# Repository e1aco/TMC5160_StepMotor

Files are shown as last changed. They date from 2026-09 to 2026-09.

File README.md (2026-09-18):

# TMC5160 步进电机驱动器

基于 STM32H750 + TMC5160 的高性能闭环步进电机驱动器，支持双电机独立控制，通过 CAN 总线通信。

## 项目状态

- ✅ 硬件验证完成（SPI 模式）
- ✅ CAN 通信协议实现
- ✅ 闭环控制（编码器反馈 + 补步）
- ✅ 散热优化：3A 持续运行温度 ≤ 70℃

## 硬件规格

| 参数 | 规格 |
|:-----|:-----|
| 主控芯片 | STM32H750VBT6（注：建议改用 STM32F103 系列） |
| 驱动芯片 | TMC5160 |
| 电机型号 | 57CME13 闭环步进电机 |
| 驱动模式 | SPI 模式（SD_MODE=0, SPI_MODE=1） |
| 采样电阻 | 0.05Ω / 1W |
| MOS 管 | AOD4126 |
| 时钟频率 | 14MHz（TMC_CLK） |
| SPI 频率 | ≤8MHz（TMC5160 最高 16/2=8MHz） |
| 通信接口 | CAN FD |
| 驱动电流 | 最大 3A（持续运行温度 ≤ 70℃） |

> **主控选型建议**：TMC5160 驱动芯片最高时钟 16MHz，SPI 最高 8MHz，无需使用 STM32H750 这类高性能芯片。建议改用 **STM32F103** 系列（如 STM32F103C8T6），成本更低且完全满足需求。当前使用 H750 属历史遗留原因。

## 软件特性

- **SPI 完全控制**：通过 SPI 接口配置 TMC5160 所有参数
- **双电机支持**：可独立控制两个电机（U1/U2）
- **多种运动模式**：
  - 绝对位置定位
  - 相对位置移动（正转/反转）
  - 速度模式持续旋转
  - 停止/刹车
- **闭环控制**：编码器反馈 + PID 补步（预留）
- **运动参数组**：预定义 4 组运动参数（低速精准/中速普通/快速/高速）
- **PID 在线调参**：支持通过 CAN 实时调整 PID 参数
- **状态反馈**：实时上报位置、状态标志、运动阶段

## CAN 通信协议

### 1. 接收命令协议 (CAN ID: `0x1AA55F42`)

| 字节索引 | 含义 | 说明 |
|:---|:-----|:-----|
| [0-3] | 值 (int32) | 4字节小端（低字节在前），含义由命令码决定 |
| [4] | 命令码 | 见下方命令码表 |
| [5] | 电机选择 | 0x01=U1, 0x02=U2, 0x06=所有电机 |
| [6] | 参数/分组 | 0x01~0x04=运动参数组（命令0x01~0x05），0x01~0x06=PID参数类型（命令0x06） |
| [7] | 校验和 | 前7字节累加取低8位 |

#### 命令码定义

| 命令码 | 名称 | [0-3] 含义 | [6] 含义 |
|:---:|:-----|:---|:---|
| 0x01 | 绝对位置移动 | 目标位置（微步） | 运动参数组 (0x01~0x04) |
| 0x02 | 相对位置正转 | 移动步数 | 运动参数组 (0x01~0x04) |
| 0x03 | 相对位置反转 | 移动步数 | 运动参数组 (0x01~0x04) |
| 0x04 | 速度模式 | 目标速度（微步/秒） | 运动参数组 (0x01~0x04) |
| 0x05 | 停止/刹车 | 0（忽略） | 运动参数组 (0x01~0x04) |
| 0x06 | PID调参 | 参数值（Q16或整数） | PID参数类型 (0x01~0x06) |

#### 运动参数组定义 (命令 0x01~0x05 使用)

| 参数组 | 说明 | VMAX | AMAX | 典型场景 |
|:---:|:-----|-----:|-----:|:---|
| 0x01 | 低速精准 | 5,000 | 1,000 | 精准定位 |
| 0x02 | 中速普通 | 20,000 | 5,000 | 日常运动 |
| 0x03 | 快速 | 50,000 | 10,000 | 快速移动 |
| 0x04 | 高速 | 100,000 | 20,000 | 长距离搬运 |

#### PID参数类型定义 (命令 0x06 使用)

| 参数类型 | 含义 | 值格式 | 默认值 |
|:---:|:-----|:---|---:|
| 0x01 | Kp（比例系数） | Q16定点数 | 8192 (0.5) |
| 0x02 | Ki（积分系数） | Q16定点数 | 2048 (0.125) |
| 0x03 | Kd（微分系数） | Q16定点数 | 4096 (0.25) |
| 0x04 | out_max（最大输出速度） | 直接整数 | 50000 |
| 0x05 | out_min（最小输出速度） | 直接整数 | -50000 |
| 0x06 | integral_max（积分限幅） | 直接整数 | 32768 |

> **Q16定点数**：实际值 = Q16值 / 65536。例如 Kp=0.5 → Q16值 = 0.5 × 65536 = 8192。

### 2. 反馈响应协议 (CAN ID: `0x1AA55F43`)

| 字节索引 | 含义 | 说明 |
|:---|:-----|:-----|
| [0-3] | 值 (int32) | 4字节小端，含义由 byte[6] 决定 |
| [4] | 标志/参数类型 | 运动反馈=状态标志位，调参反馈=参数类型 |
| [5] | 电机选择 | 0x01=U1, 0x02=U2 |
| [6] | 反馈类型 | 0x01~0x05=运动反馈，0x06=调参反馈 |
| [7] | 校验和 | 前7字节累加取低8位 |

#### 运动反馈 (byte[6] = 0x01~0x05)

| 字节索引 | 含义 | 说明 |
|:---|:-----|:-----|
| [0-3] | 位置值 (int32) | 当前电机 XACTUAL 绝对位置 |
| [4] | 状态标志位 | bit0=到位, bit1=堵转, bit2=过温, bit3=驱动错误, bit4=SPI异常 |
| [5] | 电机选择 | |
| [6] | 运动阶段 | bit0=加速, bit1=匀速, bit2=减速, bit3=归零等待, bit4=静止锁轴 |
| [7] | 校验和 | |

**状态标志位 (byte[4]) 详解：**
```
bit0 → 0=运动中，1=已到位
bit1 → 0=正常，1=堵转/失步
bit2 → 0=正常，1=过温告警
bit3 → 0=正常，1=驱动错误
bit4 → 0=SPI正常，1=SPI通讯异常
bit5-7 → 保留
```

#### 调参反馈 (byte[6] = 0x06)

| 字节索引 | 含义 | 说明 |
|:---|:-----|:-----|
| [0-3] | 参数值 (int32) | 刚设置的参数值 |
| [4] | 参数类型 | 0x01=Kp, 0x02=Ki, 0x03=Kd, 0x04=out_max, 0x05=out_min, 0x06=integral_max |
| [5] | 电机选择 | |
| [6] | 固定 0x06 | 标识为调参反馈 |
| [7] | 校验和 | |

#### 反馈发送规则

| 命令码 | 发送时机 |
|:---:|:---|
| 0x01/0x02/0x03 | 立即发送启动反馈 + 到位后发送到位反馈 |
| 0x04/0x05 | 仅立即发送一次 |
| 0x06 | 立即发送调参确认反馈 |
| 异常 | 堵转/过温/驱动错误/SPI异常状态变化时，5ms定时器触发发送 |

## 构建说明

### 环境要求

- CMake 3.20+
- ARM GCC 工具链 (`arm-none-eabi-gcc`)
- STM32CubeMX（可选，用于重新生成初始化代码）

### 编译步骤

```bash
cd Firmware/TMC5160H7Cmake_StepMotor

# 使用 CMake Presets 配置（推荐）
cmake --preset gcc-arm-none-eabi
cmake --build build

# 或手动配置
mkdir build && cd build
cmake -DCMAKE_TOOLCHAIN_FILE=../cmake/gcc-arm-none-eabi.cmake ..
make -j4
```

### 烧录

- 使用 STM32CubeProgrammer 通过 SWD 烧录
- 或使用 J-Link：`JLinkExe -device STM32H750VBTx -if SWD -speed 4000`

## 目录结构

```
ELACO_StepMotorTMC5160/
├── Firmware/
│   └── TMC5160H7Cmake_StepMotor/
│       ├── CMakeLists.txt          # 主 CMake 配置
│       ├── CMakePresets.json        # CMake 预设
│       ├── Core/                    # STM32 HAL 核心代码
│       │   ├── Inc/                 # 头文件
│       │   └── Src/                 # 源文件
│       ├── Drivers/                 # STM32 HAL 驱动库
│       ├── module/
│       │   ├── app/                 # 应用层
│       │   │   ├── motor_ctrl.c     # 电机控制接口
│       │   │   └── closed_loop.c    # 闭环控制模块
│       │   ├── algo/                # 算法层
│       │   │   └── pid.c            # PID 算法
│       │   └── drv/                 # 驱动层
│       │       ├── tmc5160.c        # TMC5160 驱动
│       │       └── can.c            # CAN 驱动
│       ├── SEGGER_RTT/              # 调试输出
│       ├── cmake/                   # CMake 工具链
│       └── test/                    # 测试代码
├── Hardware/
│   └── StepMotor_2Routes_TMC5160/   # Altium Designer 硬件设计
├── Reference/                       # 参考资料
└── README.md
```

## 理论参考

### 1. 原理图设计要点

1. **电源设计**：VSA 与 VS 由一路供电时最安全；若 VS 超过 24V，VSA 应使用单独的开关电源
2. **MOS 管选型**：
   - 选择适合电机电压（峰值+5~10V余量）和最大电流的 MOSFET
   - Vth 选择 10V 以内（TMC5160 驱动电压约 10V）
   - 根据米勒电荷选择栅极电阻（AOD4126: 10nC → 10Ω 栅极电阻）
3. **保护电路**：BM 引脚到地建议添加 TVS 二极管，避免低于 -5V 的峰值

### 2. PCB 布线要点

1. 采样电阻和滤波电容尽可能靠近功率 MOSFET
2. TMC5160 靠近 MOSFET 放置，短线互连
3. 所有 GND、GNDA、GNDD 连成公共地
4. 做好芯片散热（内部 LDO 功耗较大）
5. MOSFET 栅极走线短而直、较宽

### 3. TMC5160 配置

- **SPI 模式**：CPOL=1, CPHA=1（模式 3）
- **数据帧**：40 位（5 字节），CS 片选定界
- **时钟配置**：14MHz 方波（84MHz / 6 = 14MHz）

## 已解决问题

- ✅ 采样电阻修改为 0.05Ω / 1W
- ✅ CE3 电容 PCB 封装修正
- ✅ 栅极电阻焊接（防止 MOS 管栅极悬空导通）
- ✅ SPI 通信实现
- ✅ CAN 通信协议实现
- ✅ 闭环控制移植
- ✅ 散热优化（3A 持续运行 ≤ 70℃）

## License

MIT

---

欢迎讨论学习，如有问题请提 Issue。

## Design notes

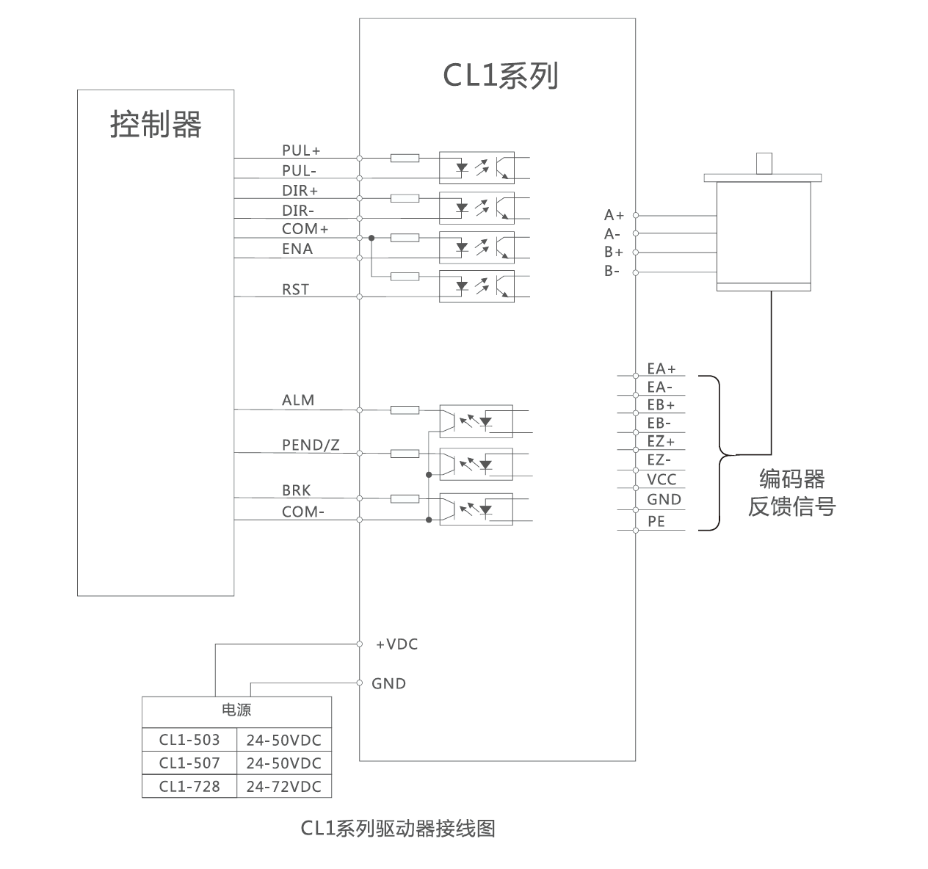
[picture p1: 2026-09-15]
Reference/接线.png

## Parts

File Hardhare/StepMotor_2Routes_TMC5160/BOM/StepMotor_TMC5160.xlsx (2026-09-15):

Comment | Description | Designator | Footprint | LibRef | Quantity | 物料代码 | 链接
2.2uF/16V | 贴片电容 | C1, C8, C17, C18, C46, C53 | C 0603_L | C | 6 | A00600123 | A03400001
104/50V | 贴片电容 | C2, C3, C4, C15, C37, C47, C48, C49, C56, C59, C10, C12, C39, C40, C42, C44C10, C12, C39, C40, C42, C44,C19, C20, C21, C22, C23, C24, C25, C26, C27, C29, C30, C31, C32, C33,C58 | C 0805_L | C | 31 | A03400669
470nF/50V | 贴片电容 | C5, C6, C7, C13, C14, C50, C51, C52, C54, C55 | C 0603_L | C | 10 | A00600157 | https://item.szlcsc.com/87156.html?c=SO&qhclickid=5d7fd4ccac5a9837&alichlgref=https%3A%2F%2Fso.szlcsc.com%2F
106/50V | 贴片电容 | C9, C11, C38, C41, C43, C45 | C 0805_M | C | 6 | A03400304
22nF/50V | 贴片电容 | C16, C57 | C 0603_L | C | 2 | A00600158 | https://item.szlcsc.com/21834.html?fromZone=s_s__%252222nf%2522&c=SO&qhclickid=5d7fd4ccac5a9837
22P/16V | 贴片电容 | C34, C35 | C 0603_M | C | 2 | A00600114
220uF/50V | 直插电解电容 | CE1, CE2, CE4, CE5 | CAP 5.0*10*12.5 - BK | CE | 4 | A00600159 | https://item.szlcsc.com/356226.html?c=SO&qhclickid=5d7fd4ccac5a9837
470uF/50V | 直插电解电容 | CE3 | CAP 5.0*10*20 | CE | 1 | A01400137 | 无库存 | https://item.szlcsc.com/54596843.html?fromZone=s_s__%2522470uF%252F50V%2522
1N4148W |  | D1, D2, D4, D5, D6, D7, D8, D9, D12, D13, D15, D16, D17, D18, D19, D20 | SOD-123 | 1N4148W_C7420318 | 16 | A01000027 | https://item.szlcsc.com/8397140.html?fromZone=s_s__%25221n4148%2522&c=SO&qhclickid=5d7fd4ccac5a9837
SMAJ28CA | TVS保护 | D3, D14 | DIODE-SMB | TVS | 2 | A01000028 | https://item.szlcsc.com/159561.html?fromZone=s_s__%2522smaj28ca%2522&c=SO&qhclickid=5d7fd4ccac5a9837
SS310 | 肖特基二极管 | D11 | SMA | SS34 | 1 | A01000029 | https://item.szlcsc.com/8397186.html?fromZone=s_s__%2522ss310%2522&c=SO&qhclickid=5d7fd4ccac5a9837
180uF/50V | 贴片电解电容 | E1 | CM E(8*10.2) | CE_SMD | 1 | A00600160 | https://item.szlcsc.com/505695.html?fromZone=s_s__%2522180uf%252050v%2522&c=SO&qhclickid=5d7fd4ccac5a9837
HDR-1X2 | 2P接插件 | JP1, JP4 | VH3.96-LI-2P | Header 2 | 2 | A01300061
HDR-1X4 | 4P接插件 | JP2, JP5 | KF350-4P | Header 4 | 2 | A00700015 | https://item.szlcsc.com/376627.html?c=SO&qhclickid=5d7fd4ccac5a9837
HDR-1X4 | 4P接插件 | JP3 | HDR2.54-LI-4P | Header 4 | 1 | A03400323
HDR-1X6 | 6P接插件 | JP6-7 | XH2.54-LI-6P | Header 6 | 1 | A03400322
68uH | 功率屏蔽电感 | L1 | IND-SMD_L5.7-W5.2_GSM0530 | L-CDRH | 1 | A01300125 | https://item.szlcsc.com/56628172.html?fromZone=s_s__%25226.8uh%2522&c=SO&qhclickid=5d7fd4ccac5a9837
红色 | 贴片LED | LED1 | LED 0805G | LED-SMD | 1 | A03400295
AOD4126 | N沟场效应管 | Q1, Q2, Q3, Q4, Q5, Q6, Q7, Q8, Q9, Q10, Q11, Q12, Q13, Q14, Q15, Q16 | TO252 | 2SK3615 | 16 | A01400174 | https://item.szlcsc.com/461587.html?fromZone=s_s__%2522aod4126%2522&c=SO&qhclickid=5d7fd4ccac5a9837
10R 1% | 贴片电阻 | R1, R2, R4, R5, R12, R13, R15, R16, R42, R43, R45, R46, R53, R54, R56, R57 | R 0603_L | R | 16 | A03400177
2R2 1% | 贴片电阻 | R3, R6, R44, R47 | R 0603_L | R | 4 | A00500176 | https://item.szlcsc.com/2177928.html?fromZone=s_s__%25222.2r%25200603%2522&c=SO&qhclickid=5d7fd4ccac5a9837
47R 1% | 贴片电阻 | R7, R11, R18, R25, R48, R52, R59, R67 | R 0603_L | R | 8 | A00500177 | https://item.szlcsc.com/3180687.html?fromZone=s_s__%252247r%2522&c=SO&qhclickid=5d7fd4ccac5a9837
0R | 贴片电阻 | R8, R9 | R 2512_L | R | 2
50mR/3W | 贴片电阻 | R10, R22, R51, R64 | R 2512_L | R | 4 | A00500178 | https://item.szlcsc.com/3159229.html?fromZone=s_s__%252250mr%25203w%2522&c=SO&qhclickid=5d7fd4ccac5a9837
0R/NC | 贴片电阻 | R14, R55 | R 0603_L | R | 2
100R | 贴片电阻 | R17, R58 | R 0603_L | R | 2 | A03400179
4.7K | 贴片电阻 | R19, R23, R24, R26, R28, R32, R33, R60, R61, R65, R66 | R 0603_L | R | 11 | A00500056
3K | 贴片电阻 | R27 | R 0603_L | R | 1 | A03400147
1K | 贴片电阻 | R34, R36, R37, R39, R68, R69, R72, R73 | R 0603_L | R | 8 | A03400181
120R | 贴片电阻 | R35, R38, R70, R71, R75, R76 | R 0603_L | R | 6 | A03400167 | 无库存 | https://item.szlcsc.com/3180501.html?fromZone=s_s__%2522120r%25200603%2522&c=SO&qhclickid=5d7fd4ccac5a9837
0R/NC | 贴片电阻 | R40, R41 | R 0805_L | R | 2
10K | 贴片电阻 | R74 | R 0603_L | R | 1 | A03400318
SW-PB | 微动开关 | S1 | SW_PB2_A1 | SW-PB | 1
TMC5160A-TA-T |  | U1, U2 | TQFP-48_L7.0-W7.0-P0.50-LS9.0-BL-EP | TMC5160A-TA-T | 2 | A01800052 | https://item.szlcsc.com/532372.html?fromZone=s_s__%2522TMC5160%2522&c=SO&qhclickid=5d7fd4ccac5a9837
STM32F407ZET6 | STM32F407ZET6 | U3 | LQFP-144_20x20x05P | STM32F407ZET6 | 1 | A03400014
XDDB-1518-0932 |  | U4, U8 | DDSUB-TH_HYC06-HDR15B-060 | XDDB-1518-0932 | 2 | A01300126 | https://item.szlcsc.com/8568600.html?fromZone=s_s__%2522XDDB-1518%2522&c=SO&qhclickid=5d7fd4ccac5a9837
XL1509-5.0E1 | 功能类型:降压型;工作电压:4.5V~40V;输出电压:5V;输出电流:2A;输出类型:固定; | U5 | SOIC-8_L5.0-W4.0-P1.27-LS6.0-BL | XL1509-5.0E1 | 1 | A01800053 | https://item.szlcsc.com/44273613.html?fromZone=s_s__%2522XL1509%2522&c=SO&qhclickid=5d7fd4ccac5a9837
AM26LV32EIDR |  | U6 | SOIC-16_L9.9-W3.9-P1.27-LS6.0-BL | AM26LV32EIDR | 1 | A03400796 | https://item.szlcsc.com/545744.html?fromZone=s_s__%2522AM26LV32%2522&c=SO&qhclickid=5d7fd4ccac5a9837
SN65HVD230QDR | 类型:CAN收发器;数据速率:1Mbps; | U7 | SOIC-8_L5.0-W4.0-P1.27-LS6.0-BL | SN65HVD230QDR | 1 | A03400034
ISL8490IBZ-T |  | U9 | SOIC-8_L4.9-W3.9-P1.27-LS6.0-TL | ISL8490IBZ-T | 1 | A03400737
AMS1117-3V3 | 三端稳压芯片 | V1, V2 | SOT223_L | AMS1117 | 2 | A03400043
8MHz | 2脚无源脚晶振 | X1 | OSC 6035-2P | XTAL-2P | 1 | A01200078 | 无库存
AMS1085CM-3.3 |  |  |  |  |  |  | https://item.szlcsc.com/46911.html?fromZone=s_s__%2522AMS1085cm%2522&c=SO&qhclickid=5d7fd4ccac5a9837
AOT470 |  |  |  |  |  |  | https://item.szlcsc.com/43270.html?fromZone=s_s__%2522aot470%2522&c=SO&qhclickid=5d7fd4ccac5a9837

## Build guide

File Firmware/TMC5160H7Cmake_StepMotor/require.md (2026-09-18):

<!-- 维护模式：本文件由 AI 维护，用户不再手动编辑。require 内容（芯片/引脚/工具链/全局目标）由访谈获取；风险确认与时序实测数据由用户直接发给 AI 登记（见 details/init.md、details/risk.md、details/tim.md）。用户口头声明变更（如"改引脚""目标变了"）→ AI 按「硬重读门」重读。-->
# 硬件资源池 (Hardware Pool)
芯片: STM32H750VBT6 (LQFP100, Cortex-M7)
晶振频率: 8 MHz (HSE, PH0/PH1)
芯片 RAM: DTCMRAM 128 KB (0x2000_0000, .data/.bss/stack)；另有 AXI 512K / RAM_D2 288K / RAM_D3 64K / ITCM 64K 未用
芯片 Flash: 128 KB (0x0800_0000)
栈大小 (Stack_Size): 1024 B (_Min_Stack_Size=0x400, 链接脚本)
关键器件:
  - 驱动芯片: TMC5160 ×2 (U1/U2, SPI 模式)
  - 外部 MOS: AOD4126
  - 采样电阻 RS: 0.05 Ω
  - 步进电机: 57CME13 (2 相, 1.8°, 4A, 1.3N·m；详细参数见 .cl/memory/config.md)
  - 编码器: 光编 1000 PPR (×4=4000cpr, 用于闭环反馈)

# 引脚固定映射表 (Pin Mapping)
> 必须为 Markdown 表格（首行表头 + `|---|` 分隔行），禁止裸文本行。

| 功能网标 | 引脚号 | 外设功能 | 说明 |
| :--- | :----- | :--- | :--- |
| HSE_IN | PH0 | RCC_OSC_IN | 8MHz 晶振输入 |
| HSE_OUT | PH1 | RCC_OSC_OUT | 8MHz 晶振输出 |
| LED_MCU | PA4 | GPIO_Output | 用户指示灯, 默认高 |
| U1_DRV_ENN | PA10 | GPIO_Output | TMC5160 #1 驱动使能(低有效), 默认高 |
| U1_SPI_SCN | PA11 | GPIO_Output | TMC5160 #1 SPI 片选(低有效), 默认高 |
| SWDIO | PA13 | DEBUG_JTMS | SWD 调试 |
| SWCLK | PA14 | DEBUG_JTCK | SWD 调试 |
| U2_DRV_ENN | PA15 | GPIO_Output | TMC5160 #2 驱动使能(低有效), 默认高 |
| FDCAN2_RX | PB12 | FDCAN2_RX | CAN 总线接收 |
| FDCAN2_TX | PB13 | FDCAN2_TX | CAN 总线发送 |
| USART1_TX | PB14 | USART1_TX | 调试串口发送 |
| USART1_RX | PB15 | USART1_RX | 调试串口接收 |
| SPI3_SCK | PC10 | SPI3_SCK | TMC5160 SPI 时钟 |
| SPI3_MISO | PC11 | SPI3_MISO | TMC5160 SPI 数据输入 |
| SPI3_MOSI | PC12 | SPI3_MOSI | TMC5160 SPI 数据输出 |
| U2_SPI_SCN | PD3 | GPIO_Output | TMC5160 #2 SPI 片选(低有效), 默认高 |
| TMC_CLK | PD14 | TIM4_CH3 | TMC5160 外部时钟(PWM 输出 15MHz) |

# 工具链池 (Toolchain Pool)
构建体系: cmake
CMake 工程: 工程根=本目录; target=TMC5160H7_StepMotor; 工具链文件=cmake/gcc-arm-none-eabi.cmake（cmake_build.py 自动探测）; 构建目录=build_cl（与 CLion 的 build/ 隔离）
编译指令: python tools/cmake_build.py <工程根> [--define 宏]   # RESULT 行=真相判据，产物 hex/elf 落 build_cl/（唯一权威 details/build.md）
IDE/编译器: CMake + GCC (arm-none-eabi-gcc) + Ninja（STM32CubeCLT）；CLion 打开同一工程用其自有 Profile
芯片型号: STM32H750VBT6
优化等级: -O0 -g3（cmake_build.py 默认 Debug 构建；Release=-Os -g0 未启用）
FPU: 单精度 + 双精度 (Cortex-M7 DP-FPU)
CubeMX 版本: 6.17.0, FW_H7 V1.13.0

# 调试与烧录 (Debug/Flash)
调试器: ST-Link (SWD, PA13/PA14)
调试回传接口: USART1 (PB14/PB15, 115200, 独立 CH340 → PC 枚举为 COMx，监听用 .cl/capture/start_mon.ps1)
启动横幅: [BOOT] TMC5160H7 StepMotor
烧录工具: ST-Link + OpenOCD (首选) / J-Link (备选)
烧录指令: python tools/openocd_flash.py --flash <工程根>\build_cl\TMC5160H7_StepMotor.hex --target stm32h7x
J-Link 烧录: python tools/jlink_flash.py --flash <工程根>\build_cl\TMC5160H7_StepMotor.hex --target stm32h750vb
复位/运行: python tools/openocd_flash.py --reset --target stm32h7x
> 残留进程兜底: python tools/openocd_flash.py --kill
> 调试通道: 主=USART1 115200；J-Link RTT 已实现但默认关（cl_config RTT_DBG=0，遥测不占 CAN 总线）；FDCAN2(500kbps) 用于命令/反馈协议

# 项目全局目标 (Global Goal) — 需求锁锚点，禁静默降级
> 每行 = 量化目标（值+单位）+ 验收判据 + 来源。AI 生成/调参/验收一律对照本节；认为不可达时禁止自行降级，须带证据请你决定（SKILL.md 约束 11）。

- 一句话定位: 双 TMC5160 独立电机控制，CAN 指令驱动，支持绝对位置/相对位置/速度三种运动模式
- 精度: 0.09°/count（光编 1000PPR ×4=4000cpr；闭环定位精度由编码器+控制算法决定，待调定后实测）
- 速度: 最高 600rpm, 加减速由 TMC5160 内部速度规划（VDCOL/TCOOLTHRS 等），暂不外部干预 | 来源: 你
- 控制周期: 待定（CAN 协议后续定义，位置环周期由 TMC5160 内部扫描）| 来源: 待定
- 负载: 待实测确定（电机 57CME13, 保持力矩 1.3N·m, 转子惯量 0.3kg·cm²）| 来源: 待实测确定
- 接口/通信: CAN 500kbps, 协议后续定义 | 来源: 待定
- 电源: 24VDC（电机建议 36V, 降额使用）| 来源: 你
- 编码器: 光编 1000PPR, ×4正交解码=4000cpr (ENC_CONST=12.8 对齐 51200微步/圈), 用于闭环反馈 | 来源: 你, 实测验证
- 验收判据: 待定（由你确定）| 来源: 你
- 优先级: 待定（由你确定）| 来源: 待定
- 首版范围 (MVP): 待定 | 来源: 待定
- 待实测确定项: 精度指标、负载工况、控制周期、验收判据、优先级、MVP 范围

# 风险与假设日志 (Risk & Assumption Log) — AI 维护，人工审核重点
> 每个 /cl run|code 收尾标 [x]/[c]/[!] 前 AI 自查 9 类高风险区并登记（规则/词表唯一权威 = details/risk.md）。无风险的任务条目末尾标 `风险:无`。

| 日期 | 任务 | 类别 | 位置 | 假设/风险点 | 可追溯到? | 状态 |
| :--- | :--- | :--- | :--- | :--- | :--- | :--- |
| 2026-09-17 | 全工程 | 安全/看门狗 | 全工程 | 无 IWDG；主循环/外设挂死或堵转时电机持续通电（已确认工程无 IWDG/WWDG） | 缺口 | [!] 待实测 |
| 2026-09-18 | 组5超高速 | 硬件时序/电气 | module/drv/tmc5160.c:94 | 组5 VMAX=2863311(50rps)在24V+传送带下必失速丢步（实测边界1200<stall≤1500rpm，U2先丢），丢步后开环位置丢失、无限位则无法0x09恢复，只能断电重建零点 | 实测 | [x] 已解决（组5已降600rpm生产档并验证PASS） |
| 2026-09-18 | 组6极限运行 | 失败路径/恢复 | module/drv/tmc5160.c:95 | 组6=1442rpm逼近U2失速边界(1471,1481]，属故意高风险运行：失速→位置丢失→断电重建；仅有人值守测试，生产帧禁用param=6，每次用后查失步位 | 推演链 | [✓] 人工确认（用户10+次复测干净，生产禁用+值守+用后查失步位三条防线已固化） |

> 类别词表(9类): 硬件时序/电气 | 实时性/竞态 | 数值溢出/定点 | 寄存器/手册 | 失败路径/恢复 | 内存/栈 | 安全/掉电 | 时序参数/经验值 | UB/可移植
> 可追溯到?: 手册 / 实测 / 推演链 / 缺口
> 状态: [ ] 待人工确认 / [✓] 人工确认 / [!] 待实测 / [x] 已解决（可归档删除）

# 时序测量表 (Timing Budget) — AI 维护，外部实测需人工回填

## 前置配置区
> 默认指标（预算比例/总利用率上限/绝对裕量/测试周期/词表）为 skill 级默认，唯一权威见 `details/tim.md`「默认指标」；项目覆盖在此改。
- 时序测试点 IO: PD14 (TMC_CLK, TIM4_CH3) — 可翻转供 Saleae/示波器捕获
- 探针默认位置: 函数级（ISR 入口/出口），语句级由条目位置列自定义覆盖

## 条目表
| 操作 | 位置/探针位置 | 理论值(依据) | 预算/判据 | 测试 | 实测值(日期) | 利用率 | 状态 |
| :--- | :--- | :--- | :--- | :--- | :--- | :--- | :--- |
| SPI3 TMC5160 读写周期 | S_SpiWrite/SpiRead 的 SelectChip→DeselectChip 全事务 | 写单事务 6.2us(40bit@6.45M)+轮询/片选开销；读双报+5us 帧间隔（SPI3=PLL3Q 103.2M÷16=6.45M, fSCK≤fCLK/2=7.5M） | fSCK 6.45≤7.5MHz 规格内；写/读事务达标 | 软件(DWT, 480MHz 基准)·每次变更都测 | 写 max 4437cyc≈9.2us / 读 max 11311cyc≈23.6us（含片选）(2026-09-17) | — | [x] 寄存器级收发+片选；HAL 旧值(/240 虚高 2×)=写20/读54 → 实~10/~27 |
| TIM4 PWM 输出 (TMC_CLK) | PD14 示波器 | 15MHz（TIM4CLK=240MHz, PSC=0/ARR=15） | 15MHz ±1% | 硬件(Saleae)·仅首次测 | 软件比值 fCLK≈15.00MHz±0.01%（SOAK r3，非仪器）(2026-09-10) | — | [!] 示波器终验欠 |
| USART1 串口回传 | PB14 TX | USART1CLK=64MHz, 115200 8N1 | — | 软件(DWT)·每次变更都测 | (待测) | — | [ ] |
| 主循环单圈 | main while(1) tag2全事务/tag5心跳块 | 空载循环体约1us；1Hz心跳块含12×SPI读约625us | —(无周期条目，不设预算) | 软件(DWT 480MHz+RTT Ch0)·抽稀500:1 | 典型1us(p50)/max2us(1105cyc,2928样)；心跳圈625us/300367cyc(1Hz,3样)(2026-09-18) | — | [x] 串口不可用改RTT回传；探针常驻生产版空宏(44600B一致) |
| SpreadCycle 斩波频率 | Rsense 两端（示波器） | ~20-25kHz（TOFF=5, TBL=3, fCLK=15MHz; f≈1/(4×tOFF), tOFF=(24+32×TOFF)/fCLK） | 16-30kHz | 硬件(Saleae/示波器)·仅首次测 | | — | [!] |
| **Σ** | | | | | | **—（无周期性条目）** | |

# 任务队列 (Task Queue) — AI 自动维护（允许为空）
> 状态标记: [ ] 未开始 / [x] AI 完成(待验收) / [✓] 人工验收通过 / [!] 阻塞 / [c] Code Only。**滚动窗口**：仅保留 未完成 + 最近 5 条已完成（更早删除；长链在 `.cl/experience/log.md`，负结论在 `memory`「定论」段，全文 git 兜底）。

## 2026-09-18
- [c] RTT 调试通道切换（UART→RTT）：cl_config.h UART_DBG→0/RTT_DBG→1 + main.c 启用 RTT_DBG_Init + rtt_dbg.c 追加 printf retarget 到 RTT Channel 0（_write 覆盖 syscalls.c weak）（起 2026-09-18 | 止 2026-09-18 | 验收 build 0E/0W FLASH 44600B）风险:无
- [✓] 丢步位置恢复（断电重建零位）：24V重上电后U2即干净，U1失步锁存又经3轮stop读后自清；单电机rel±验证双电机终态bit0=1无失步；rel-U1两次丢帧经对照实为PCAN transient（同窗stop/rel-ALL/单电机复测全通），非固件通路（起 2026-09-18 | 止 2026-09-18 | 验收 双电机终态干净+单步 motion OK）风险:无
- [✓] 6组加减速优化（VMAX冻结；G1~G5取40000试探干净×0.7=28000，G6取40000×0.98=39200；DMAX对称跟随；正反各2趟+终验12腿全bit0=1无失步；G5行程1.28→1.22s/G6 1.27→1.18s符合加速理论；40000以上未探留容缺）（起 2026-09-18 | 止 2026-09-18 | 验收 终验12/12 PASS）风险:无
- [✓] 精测边界+Group6固化（U2正反转边界收敛(1462,1481]，U1(1500,1572]；Group6=1442rpm=1471×0.98；U1精确边界留容缺）（起 2026-09-18 | 止 2026-09-18 | 验收 边界收敛+G6 PASS）风险:见风险日志"组6极限运行"行
- [✓] 最高不卡死速度二分（vel+RTT enc冻结判据）：U2∈(1462,1481]rpm、U1∈(1500,1572]rpm，U2为弱电机；生产600rpm裕量2.4倍以上（起 2026-09-18 | 止 2026-09-18 | 验收 边界收敛+双电机失步确认）风险:无
- [✓] 组5处置固化（s_profiles[4]→600rpm VMAX=572303/AMAX=28000+推导注释）（起 2026-09-18 | 止 2026-09-18 | 验收 PASS）风险:无

# 附录 A: CAN 命令协议 — 来源: 源工程 can_drv/can_usr 实现
> 收发模型：经典帧 / 扩展 ID / 8 字节 / 500kbit/s；硬件过滤器只收命令 ID 进 RX FIFO0，其余丢弃；
> 中断入队 → 主循环 `CAN_Process()` 逐条分发（实现见 module/drv/can.c）。
> 校验和：byte7 = (byte0+…+byte6) & 0xFF（收发同算法，不符的帧丢弃）。

## 命令帧 0x1AA55F42 (上位机 → MCU)

| byte | 字段 | 说明 |
| :--- | :--- | :--- |
| 0-3 | value | int32 小端；含义随 cmd 变（见下表） |
| 4 | cmd | 命令码 0x01~0x0A（见下表） |
| 5 | motor | 0x01=U1 / 0x02=U2 / 0x06=全部（0x09 回零仅接受 U1/U2） |
| 6 | param | 运动参数组 ID 1~6（cmd 0x06 时为 PID 参数类型；0x09 时预留忽略；组6=1442rpm 极限运行档，生产禁用，见组6注记） |
| 7 | checksum | 见上 |

| cmd | 名称 | value 含义 | 执行动作 | 反馈时机 |
| :--- | :--- | :--- | :--- | :--- |
| 0x01 | 绝对定位 | 目标绝对位置 µsteps | 按 param 组运动到 value | ACK（bit0=0）+ 到位后补终态帧 |
| 0x02 | 相对顺时针 | 偏移量 µsteps（正数） | 从当前位置 +value | 同上 |
| 0x03 | 相对逆时针 | 偏移量 µsteps（正数） | 从当前位置 −value | 同上 |
| 0x04 | 速度模式 | 目标速度=斜坡寄存器原值（符号=方向，+正/−反；物理µsteps/s=值×fCLK/2^24，fCLK=15MHz时物理=值/1.1178；如600rpm=512000µsteps/s对应值572303，实测闭合2026-09-18） | 持续旋转 | 收到即回一帧（无目标，无终态） |
| 0x05 | 停止 | 忽略 | 切定位模式锁轴 | ACK（bit0=0）+ 静止后补终态帧 |
| 0x06 | PID 调参 | — | 未实现（收到丢弃，无反馈） | 无 |
| 0x07 | 闭环使能 | 忽略 | 使能该电机闭环 | 收到即回 ACK（全 0） |
| 0x08 | 闭环禁用 | 忽略 | 禁用该电机闭环 | 收到即回 ACK（全 0） |
| 0x09 | 无编码器回零 | bit0=方向（0=负向，1=正向），其余位保留 | StallGuard2 碰限位回零（异步） | 启动成功回 ACK，**完成时再发终态帧** |
| 0x0A | 急停 | 忽略 | 拉高 ENN 关功率级，自由停车（不锁轴） | 收到即回 ACK |

> cmd 0x09 回零语义：motor 仅 U1/U2（0x06 拒绝）；忙中/非法参数不回 ACK，上位机可重发；
> 终态反馈 status bit0=到位（成功）/ bit1=失步（失败）；执行见 module/app/homing.c。
>
> cmd 0x0A 急停语义：motor 可为 U1/U2/0x06（全部）；value/param 忽略；
> 急停后位置已丢失——后续运动命令（0x01~0x04/0x09）会自动重使能，但必须先发 0x09 重回零，否则运动基准不可信。

## 反馈帧 0x1AA55F43 (MCU → 上位机)

| byte | 字段 | 说明 |
| :--- | :--- | :--- |
| 0-3 | pos | 编码器位姿 X_ENC，int32 小端（ACK 类反馈填 0） |
| 4 | status | bit0=到位（RAMP_STAT bit9，读后清）/ bit1=失步（ENC deviation_warn）/ bit2=过温（OTPW/OT）/ bit3=驱动错（GSTAT drv_err，读后清）/ bit4=SPI 异常（读回 0xFFFFFFFF/0 判活失败） |
| 5 | motor | 回显命令中的 motor |
| 6 | protect | bit0=OTPW / bit1=OT / bit2=drv_err / bit3=S2GA / bit4=S2GB / bit5=S2VSA / bit6=S2VSB / bit7=失步（编码器偏差） |
| 7 | checksum | 见上 |

> 反馈时机：定位类命令（0x01/0x02/0x03/0x05）先回 ACK（bit0 强制 0），主循环检到 XACTUAL==目标且速度归零后再发终态帧（bit0 真实）；30s 未到也发一帧当时快照（上位机判超时）；
> 速度模式（0x04）无目标只有即时帧；回零（0x09）ACK + 终态双帧不变。

# 附录 B: 工作流程 (项目意图)
- 两路电机分别回零（无编码器 StallGuard2 回零，SPI 轮询判完成）；一路到位后 CAN 控制第二路回零；完成后上报
- 回零完成后接受相对/绝对/速度运动指令；所有模式限制在 [0, 最大目标值] 内，越界上报（防堵转/不可控）
- 两电机位置互不干涉的仲裁方式待定（上位机 or MCU）
- 功能轮子: ①上电回零（速度+方向→堵转确认零点→反向几微步防卡死→置零）②相对/绝对/速度模式（已有）③堵转/过流保护（运行中堵转立即停+反向几步）④梯形/线性规划（已有，待评估 S 型）⑤闭环位置控制（已有，待调）⑥CAN 通讯（已有，协议待完善）⑦SPI 读写 TMC5160（已有，寄存器级实测 9.2/23.6us）

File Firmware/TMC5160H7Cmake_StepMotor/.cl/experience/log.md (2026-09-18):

# 调试日志

> **滚动窗口**：log.md 只存「活性记录 + 最近进行中」——已封存条目随 `/cl end` 精简删除（git 历史兜底）。
> **价值三层模型**：结论层→require.md/.cl/memory；条件层→诊断案例或 details/tools；过程层→本文件。
> **精简判据/提升规则** 见 templates/log.md。

## [2026-09-18] 任务: 双TMC5160 速度极限/边界/加速度全链路验证 — /cl end 验收通过
- **模式**: /cl run（全自动闭环；多阶段：速度二分→边界收敛→加速度上推→生产固化）
- **现象**: 24V+传送带，U2=弱电机。vel模式RTT enc冻结判据有效，二分收敛U2∈(1462,1481]rpm/U1∈(1500,1572]rpm。端序坑：用户帧BE读错导致-939M/367s假失步，实为PCAN transient（stop/rel-ALL/单电机复测全通）。ENC_TOLERANCE 256→512解决G6 1442rpm巡航跟随滞后263µsteps误报。失步=永久XACTUAL偏移，每次失速须24V断电重建。ST-Link失联（OpenOCD "open failed"），全程J-Link烧录。
- **尝试**:
  - 速度二分：vel模式+RTT enc冻结→1350双过→1425双过→1462双过→1481U2丢U1过，收敛到U2∈(1462,1481]/U1∈(1500,1572]rpm
  - 端序定位：PCAN用户帧BE读错（-939M），修正后LE帧与固件一致；"丢步"实为PCAN transient（同窗stop/rel-ALL复测全通）
  - ENC_TOLERANCE：G6 1442rpm巡航enc lag=263µsteps>256阈值误报失步，升到512后复测干净；刻意失速验证1572rpm仍正确检测
  - Group6定值：1442rpm=1471×0.98（U2弱电机边界内），用户10+次复测无异常
  - 加速度上推：40000全组零丢步×6组×4腿=24腿全干净（含G6@30000/@40000各4腿）；G5/G6行程时间严格单调递减验证AMAX生效
  - 固化：G1~G5=28000（×0.7）,G6=39200（×0.98）,DMAX=AMAX对称
- **最终方案**: VMAX冻结（G1:5000/G2:20000/G3:50000/G4:100000/G5:572303/G6:1375452），AMAX=DMAX（G1~G5:28000/G6:39200），ENC_TOLERANCE=512，Group6生产禁用param=6+值守+用后查失步位
- **验证结果**: ✅ 二分边界收敛（双电机失步确认）；✅ 加速度终验12/12腿bit0=1无失步；✅ G5行程1.28→1.22s/G6 1.27→1.18s；format 0FAIL/build 0E/0W/FLASH 44636B
- **经验引用**: PCAN transient≠固件bug（工具坑→run-fault.md）；ENC_TOLERANCE必须覆盖最大巡航滞后（263→512µsteps）；开环失步=永久偏移须断电重建（非stop可恢复）；AMAX 40000全组干净但真临界未知（收益递减边界G1仅0.03%加速占比）
- **提示词压缩**: `[STM32H750/TMC5160 24V传送带] [vel二分+RTT enc冻结判据] [U2∈(1462,1481] U1∈(1500,1572] 600rpm裕量2.4×] [AMAX×0.7=28000/G6×0.98=39200 终验12/12] [J-Link烧录+PCAN transient≠固件]`
- **违规自检**: ✅已读 run+codegen+watcher+preflight+probe+tim+build+flash+format-gate+risk+run-fault+end；✅全自动闭环；✅澄清+用户裁决后才生成；✅工具问题按run-fault处理；违规记录：无

## [2026-09-17] 任务: SPI 寄存器级收发+片选改造（含 DWT 基准修正）— /cl end 验收通过
- **模式**: /cl run（全自动闭环；中途按用户裁决追加"片选寄存器级"与"SPE 常开 A/B 实验并回退"）
- **现象**: 需求=SPI 收发/片选走寄存器级提速。HAL 基线(旧表 /240 基准)=写 20us/读 54us；寄存器级实测(DWT 修正 480MHz 后)=写事务 4437cyc≈9.2us / 读事务 11311cyc≈23.6us(含片选)
- **尝试**:
  - 澄清 Q1-Q4（仅换收发/临时开自检作判据/跑时序门禁/扫描串口）→ 生成 S_SpiTransfer（H7 high-end 序列 TSIZE→SPE→CSTART→轮询 TXP/RXP→等 EOT→清 IFCR），替换 SpiWrite/SpiRead/DebugTransfer
  - 功能判据先过：`[SPI OK] tested U1+U2 link`（双芯 CHOPCONF=0x000181C5 回读 + GCONF 写读回显）
  - 用户追加：片选改 `GPIOx->BSRR` 寄存器级 → 读事务中位 48.99→47.13us(/240 基准)
  - 发现 DWT 基准错：OpenOCD 自由运行读 CYCCNT 962.5Mcyc/2s≈481MHz → `tim_test.c` /240 改 /480；`S_DelayUs` 同步(tCSH 标称 10→5us 保持实际时序)
  - SPE 常开 A/B：tag0 4437→4373cyc / tag1 ~0 → 无收益，用户裁决回退
  - 生产版还原(宏关+COMM_Test_SPI 还原)烧录：boots=8 心跳健康无 [TM]
- **最终方案**: 寄存器级 S_SpiTransfer(逐帧 SPE) + 寄存器级片选 BSRR + DWT 480MHz 基准修正；生产版 FLASH 44928B
- **验证结果**: ✅ 功能 [SPI OK] 双芯；时序表 [SPI3] 条回填 [x]；format_gate 0 FAIL / build 0E/0W
- **经验引用**: memory += `spi_spe_always_on_no_gain` / `stm32_dwt_cyccnt_clk` / `tmc5160_tCSH` 修正；工具坑=cmake_build.py GBK 崩溃、OpenOCD SWD IDCODE 瞬态失败(重试恢复)
- **提示词压缩**: `[STM32H750/SPI3+TMC5160] [寄存器级收发:TSIZE→CSTART→轮询TXP/RXP→等EOT] [片选GPIOx->BSRR] [DWT基准=CPU=480MHz] [判据[SPI OK]+[TM]写9.2/读23.6us]`
- **违规自检**: ✅已读 run/codegen/watcher/preflight/probe/tim/build/flash/format-gate/risk/run-fault/end；✅全自动闭环；✅澄清+用户裁决后才生成；✅工具问题按 run-fault 处理；⚠️过程教训：时序门禁应"功能判据先过再测 [TM]"（初次先建宏版测量，经用户纠正）

## [2026-09-11] 任务: 电机运行排查 B 相 s2gb — /cl end 验收通过（根因=RS-B Kelvin 跳线错位）
- **模式**: /cl run（静音轮→手册基线轮→降频轮→回归轮，共 5 版固件）+ 硬件侧用户排查
- **现象**: 承 09-10 未结案；新增：StealthChop 报 s2vsb+olb（ds=40146000）；手册基线轮电机首次位移 8717(17%)后锁（ds=D1140067）；12MHz 轮 enc=3072(6%)更差；用户实测链：HB2-BMB2=0、A 栅 4.5V/B 栅 22V、桥阻对称、换片换电容 MOS 完好、空载全导通、电源无跌落、线圈对调故障不离桥、B 下管也不导通
- **尝试**:
  - 静音轮(`COMM_Test_SPI_Quiet`, GCONF=0x04)：FAIL act=17801 enc=13 ds=40146000(s2gb=0,s2vsb+olb=1) → 斩波模式无关
  - 手册基线轮(`COMM_Test_ManualRun`, CHOPCONF=0x000100C5+DRV_CONF 复位缺省)：FAIL act=33321 enc=8717 ds=D1140067 → 斩波/drvs 维度穷尽；附带修钩子 bug（绝对目标撞 XACTUAL 编码器同步起始位→改相对+51200，到位比较改绝对变量）
  - 降频轮(15→12MHz, SPI/32)：FAIL enc=3072 更差 → "下管充电不足"假设否决 → 用户放弃，回退 15MHz/6.45M（[TM] 复验写20us/读54us 与 09-09 一致）
  - ch11.p079 核对：短路响应=**分桥关断**(B 整桥 HS+LS 全停、A 继续) → "B 下管不导通"=同一跳闸之果；双检测器齐跳(s2gb+s2vsb)=回路整体过流 → 嫌疑重排首位=采样通路（修正上轮"全局关断"说法）
  - 用户硬件侧穷尽：换片✗换电容✗MOS✗电源✗对调不离桥 → 最终查出**板铺铜破坏 RS-B Kelvin(SRBH/SRBL)走线 + 补救跳线错位**（修复确认）
- **最终方案**: 硬件修正跳线；固件生产 init 本就正确无改动；测试钩子(`SPI_MANUAL`/`SPI_QUIET`)验收后删除归位生产版
- **验证结果**: ✅ 15MHz 宏版 ManualRun **连续 2× `[MNLRUN PASS] reached=1 act=51200 enc=51200`（一整圈零丢步）`ds=81140061 gs=00`**；生产版(SPI_MANUAL=0)已烧，心跳 act=102400 enc=0 锁轴 gs=00 健康
- **经验引用**: memory 新增 10 条（quiet_s2vsb/manual_partial/hb2_zero/gate_rail/fclk12_rejected/noload_cleared/follows_bridge/per_bridge_shutdown/kelvin_jumper_fixed/regression_pass）；违规自检：无（run 全自动/先澄清后生成/未降判据/工具问题按 run-fault 处理）
- **提示词压缩**: `[TMC5160 s2gb 空载好带载锁] [先查采样通路RS/SRBH/SRBL再查驱动] [分桥关断A活B灭] [ManualRun相对整圈判据] [跳线修复+回归PASS]`

## [2026-09-12] 任务: 生产配置 SpreadCycle 整圈运行验证（无错误标志）— /cl end 验收通过
- **模式**: /cl run（第 1 轮直 PASS，无迭代）
- **现象**: 用户要求非静音模式 + 运转全程无错误标志；查生产 init 本就 GCONF=0x00 SpreadCycle（零生产代码改动，任务本质为物理验证）
- **尝试**:
  - 生成：新增宏门控钩子 `COMM_Test_ProdRun`（test/comm_test.c，不重写斩波，仅 ApplyProfile(4)；GCONF=0x00 门控确认；判据=reached 且 |enc|≥25600 且 s2g/s2vs/ol 全 0 且 drv_err=0）+ `SPI_PRODRUN`（cl_config.h）+ main.c 上电段接线；format 门禁顺手收敛旧超宽行 534
  - 编译：cmake_build.py 0E/0W；时序预检未命中（未改 drv/时钟/while 体）
  - 烧录监听：COM8(CH340 独立 UART)+ST-Link/openocd 直调（wrapper --search 失效，见经验）；watcher 一次读 status 即命中
- **最终方案**: 生产配置验证通过即归位（SPI_PRODRUN→0，重编重烧生产版）
- **验证结果**: ✅ `[PRODRUN PASS] reached=1 act=51200 enc=51200(一整圈零丢步) ds=8114007E(s2g/s2vs/ol 全 0) gs=00`；生产版 boots=2 心跳健康
- **经验引用**: 诊断案例不入库（1 轮直中，不满足判据①）；工具坑 3 项修 skill（openocd_run.py --search 透传；烧录反斜杠路径；start_mon -Tools 探测）；过程项仅本 log
- **提示词压缩**: `[STM32H750/TMC5160 生产SpreadCycle] [GCONF=0x00+ApplyProfile(4)相对整圈] [ds掩码0x38003000+gs全0+enc跟随] [PRODRUN钩子+宏归零重烧] [首轮PASS]`
- **违规自检**: ✅已读 run/watcher/preflight/flash/run-fault/end；✅全自动闭环未推手动；✅澄清后生成；✅无静默降级（最严判据档）；✅工具问题按 run-fault 处理；违规记录：无

## [2026-09-12] 任务: CAN 回零/急停/到位反馈闭环实测 + 失步标志猎捕 — 部分通过
- **模式**: /cl code（回零/急停/反馈逻辑）+ /cl run（CAN 实测 20+ 连测）
- **现象**: 回零缺机械条件；失步 flag 用户偶现、26 轮零复现
- **尝试**:
  - 回零逻辑：app/homing.c 状态机 + CAN 0x09 + memory 回零参数段；编译 0E/0W
  - 急停 0x0A + 反馈 bit0 去残留 + 终态补帧：编译 0E/0W
  - T1 反馈双帧 PASS / T2 急停恢复 PASS（急停漂移 985µsteps）/ T3 回零双向 60 转超时（SG 60 点恒定 226~272；修终态重启动 busy bug）
  - 失步猎捕：早/正常抢占、速度切换、精确复现帧三档 gap 全干净；20 连测 20/20 全干净（60 帧）
- **最终方案**: 回零/失步阻塞等条件与数据；急停/反馈按实测 PASS 生效
- **验证结果**: ✅ T1/T2；❌ 回零（无硬限位迹象，SGT 初估 −5）；❌ 失步复现（26 轮零）
- **经验引用**: 诊断案例不入库（无根因，不满足判据②）；skill 固化 can_monitor --hexdump + can_send home/estop 快捷（本轮已修验）；过程项仅本 log
- **提示词压缩**: `[STM32H750/TMC5160 CAN闭环] [0x09回零+0x0A急停+终态补帧] [PCAN同句柄收发+二进制解码] [T1T2过回零失步阻塞] [20连测全净]`
- **违规自检**: ✅全自动（20 连测无人值守）；✅澄清后生成；✅无静默降级（阻塞如实[!]/[c]）；✅工具坑走 skill 固化；违规记录：无

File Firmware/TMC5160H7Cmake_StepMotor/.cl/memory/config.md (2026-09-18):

# .cl/memory/ — 配置推导值（terse）

> 写纪律见 `details/init.md`「memory 写纪律」：一行一条 `key = value  @依据  #来源  日期` / 只留当前有效值 / ≤200 行·12KB。
> `@` = 寄存器/位 / datasheet 章节 / 器件规格书 / 上游 memory key；`#` = 推导·实测·实测校准·你·datasheet·CubeMX·代码核对·待实测确认。
> 排查过程（s2gb/Kelvin）→ `experience/log.md`；全量快照见 git 8db5a7b。

## 定论（已否决 / 已解决）
spi_speed_downgrade = 否决: 6.45Mbps 过快致位翻转(降速论证伪)  @SOAK r3 0 翻转  #实测  2026-09-10
tmc_clk_12m_s2gb = 否决: 降 12MHz 可解 s2gb(enc=3072 更差)  @log 09-11  #实测  2026-09-11
u2_s2gb_sw = 否决: s2gb 属软件问题(斩波双模式+DRVS×CS+SPI 降速全穷尽)  @log 09-10/11  #实测  2026-09-11
spi_spe_always_on = 否决: SPE 常开可省时(A/B tag0 -0.13us≈0)  @实测  #实测  2026-09-17
u2_s2gb = 已解决: B 相 100%丢步, 根因 RS-B 开尔文走线被铺铜破坏+跳线错位  @ManualRun 2×整圈零丢步  #你定案  2026-09-11

## 电机参数 (57CME13)
motor_phases = 2  @电机规格书  #推导  2026-08-24
motor_hold_torque = 1.3 N·m  @电机规格书  #推导  2026-08-24
motor_step_angle = 1.8°  @电机规格书(200步/圈)  #推导  2026-08-24
motor_rated_current = 4 A  @电机规格书  #推导  2026-08-24
motor_phase_resistance = 0.42 Ω  @电机规格书  #推导  2026-08-24
motor_phase_inductance = 1.6 mH  @电机规格书  #推导  2026-08-24
motor_rotor_inertia = 3e-5 kg·m²  @0.3kg·cm²换算  #推导  2026-08-24
motor_weight = 0.8 kg  @电机规格书  #推导  2026-08-24
motor_fullsteps_per_rev = 200  @1.8°步距角  #规格书  2026-08-24
motor_microsteps = 256  @CHOPCONF.MRES  #推导  2026-08-24
motor_counts_per_rev = 51200  @200×256  #实测  2026-09-01

## MOSFET (AOD4126)
mosfet_vds = 100 V  @AOD4126  #推导  2026-08-24
mosfet_id_max = 43 A  @AOD4126 @VGS=10V  #推导  2026-08-24
mosfet_rds_on = 24 mΩ  @AOD4126 @VGS=10V typ  #推导  2026-08-24
mosfet_qg = 28 nC typ  @AOD4126  #推导  2026-08-24
mosfet_qgd = 10 nC typ  @AOD4126  #推导  2026-08-24
mosfet_vgs_th = 3.3 V typ  @AOD4126  #推导  2026-08-24

## 外围电容 (TMC5160A 应用)
board_bootstrap_cap = 470 nF ×4  @Qg>20nC→470nF, 每半桥一只  #推导  2026-09-10
board_12vout_cap = 10 µF  @≥10×自举电容→取上限  #推导  2026-09-10
board_pump_caps = CPI-CPO 22nF/100V, VCP-VS 100nF/16V  @ch02.p013  #datasheet  2026-09-10
board_vs_bulk_cap >= 100µF/A  @ch03.p015(4A→≥400µF)  #datasheet  2026-09-10

## TMC5160 驱动配置
tmc5160_rs = 0.05 Ω  @硬件资源池  #你  2026-08-24
tmc5160_vfs = 0.325 V  @ch28(VSRT)  #推导  2026-08-24
tmc5160_ifs = 6.5 A  @VFS/RS  #推导  2026-08-24
tmc5160_globalscaler = 256  @init 未写 GLOBALSCALER(复位默认)  #代码核对  2026-09-10
tmc5160_irun = 20  @IHOLD_IRUN; (20+1)/32×6.5/√2=3.02A RMS  #实测校准  2026-09-01
tmc5160_ihold = 6  @IHOLD_IRUN; (6+1)/32×6.5/√2≈1.01A(0.33N·m); 3 锁不住回调  #实测  2026-09-10
tmc5160_ihold_delay = 8  @IHOLD_IRUN.IHOLDDELAY; 2^18×8/15MHz≈140ms  #代码核对  2026-09-10
tmc5160_tpowerdown = 40  @TPOWERDOWN; 2^18×40/15MHz≈699ms  #代码核对  2026-09-10

## TMC5160 时钟
tmc5160_clk_source = external  @PD14 TIM4_CH3 PWM  #你  2026-08-24
tmc5160_clk_freq = 15 MHz  @TIM4 PWM; XACTUAL 17881/s 匹配 15.00MHz±0.01%  #实测  2026-09-11
tmc5160_spi_max_sck = 7.5 MHz  @ch4 fSCK=fCLK/2  #推导  2026-09-11

## TMC5160 SPI 配置
tmc5160_spi_mode = 3  @ch4 (CPOL=HIGH,CPHA=2EDGE)  #推导  2026-08-24
tmc5160_spi_datasize = 8-bit  @40bit 数据报=8bit 地址+32bit 数据  #推导  2026-08-24
stm32_spi_prescaler = 16  @SPI3 kernel PLL3Q 103.2MHz ÷16=6.45MHz  #实测校准  2026-09-11
stm32_spi_baudrate = 6.45 Mbit/s  @103.2MHz/16; 寄存器级写 9.2us/读 23.6us  #实测校准  2026-09-17
stm32_spi_kernel_clk = 103.2 MHz  @PLL3 HSE8/M5 ×N129 /Q2  #CubeMX  2026-09-09
tmc5160_tCSH_us = 5  @ch04 §4.3 (2×tCLK+10ns=320ns); 帧后加 5us  #datasheet  2026-09-17

## TMC5160 通讯事实
tmc5160_spi_status_byte = 0x38  @ch04 §4.1.2 (byte[39:32], 静止=0x38)  #datasheet+实测  2026-09-09
tmc5160_ihold_irun_readable = false  @ch05.p038 (只写, 回读恒 0)  #datasheet+实测  2026-09-09
tmc5160_enc_const_readable = false  @ENC_CONST 标 W; 保真测试用 XTARGET  #datasheet+实测  2026-09-10
tmc5160_spi_fidelity_6p45M = verified  @SOAK r3 XTARGET 222170 帧 0 翻转  #实测  2026-09-10
tmc5160_spi_all_zero_reads = 无 VM 供电时 MISO 恒 0  @判活须用非零签名  #实测  2026-09-10
u1_chip_populated = true  @U1 已焊 + SPI/CAN 测试通过  #实测  2026-09-16

## 无编码器回零 (StallGuard2)
home_velocity_rps = 2  @ch13 §13.4 (1~5RPS)  #推导  2026-09-12
home_vmax = 114532  @V=2×51200; 102400×2^24/15e6  #推导  2026-09-12
home_amax = 20000  @与参数组4同量级 → a≈2.05M µsteps/s²  #推导  2026-09-12
home_tcoolthrs = 200  @ch13 §13.1 (TSTEP≈146→取 200)  #推导  2026-09-12
home_sgt = 0  @ch13 §13.1 起始值; 阈值待真机调定  #待实测确认  2026-09-12
home_sg_confirm = 8  @连续零确认抗抖  #你  2026-09-12
home_backoff = 2048 microsteps  @防卡死  #你  2026-09-12
home_sg_poll_ms = 2  @fullstep 周期@2RPS=2.5ms  #推导  2026-09-17
home_run_timeout_ms = 30000  @机械行程未知 → 30s 兜底  #待实测确认  2026-09-17
home_bo_timeout_ms = 10000  @回退 2048≈64ms → 10s 兜底  #待实测确认  2026-09-17

## 编码器配置
encoder_ppr = 1000 PPR  @ENC_CONST=12.8 反推 200×256/12.8=4000cpr÷4  #实测  2026-09-01
encoder_cpr = 4000 counts/rev  @1000PPR ×4 正交  #推导  2026-09-01
encoder_resolution = 0.09°/count  @360°/4000  #推导  2026-09-01
encoder_enc_const = 12.8  @ENC_CONST=FSC×USC/cpr  #推导  2026-09-01
encoder_encmodes = 0x00  @源工程 ENCMODE 写入值  #源工程  2026-09-01
encoder_tol = 512 microsteps  @TMC5160_ENC_TOLERANCE  #实测  2026-09-18
encoder_lag_max = 263 microsteps  @G6 1442rpm巡航跟随滞后(到位回落Δ13)  #实测  2026-09-18

## TMC5160 栅极驱动 / 斩波
tmc5160_drvstrength = 2  @AOD4126 Qgd=10nC(中等强度)  #推导  2026-08-24
tmc5160_bbmtime = 16  @死区 200ns typ 防直通  #推导  2026-08-24
tmc5160_chopconf = 0x000181C5  @CHOPCONF; TOFF=5/HSTRT=4/HEND=3/TBL=3/MRES=0  #代码核对  2026-09-10
chopper_toff = 5  @ch01.p052 CHOPCONF[3:0]  #推导  2026-08-24
chopper_tbl = 3  @CHOPCONF[16:15]=54clk  #代码核对  2026-09-10
chopper_hstart = 4  @CHOPCONF[6:4]  #代码核对  2026-09-10
chopper_hend = 3  @CHOPCONF[10:7]  #代码核对  2026-09-10

## FDCAN2 配置
fdcan2_baud = 500 kbit/s  @NominalPrescaler=1/Seg1=13/Seg2=2, 16TQ@8MHz  #CubeMX  2026-09-16
fdcan2_autoretransmit = ENABLE  @CubeMX  #CubeMX  2026-09-16
fdcan2_msgram = EF=1/RxFifo0=8/TxFIFO=3  @CubeMX 重生成需保留  #源工程  2026-09-16

## STM32 时钟树
stm32_hse = 8 MHz  @.ioc  #推导  2026-08-24
stm32_sysclk = 480 MHz  @PLL1 8/1×120/2  #推导  2026-08-24
stm32_hclk = 240 MHz  @HPRE=DIV2  #推导  2026-08-24
stm32_apb1 = 120 MHz  @D2PPRE1=DIV2  #推导  2026-08-24
stm32_apb2 = 120 MHz  @D2PPRE2=DIV2  #推导  2026-08-24
stm32_tim4clk = 240 MHz  @APB1×2  #推导  2026-08-24
stm32_spi3clk = 103.2 MHz  @PLL3Q(2026-09-09 改)  #CubeMX  2026-09-17
stm32_dwt_cyccnt_clk = 480 MHz  @DWT=CPU=SYSCLK(D1CPRE=1); 实测 481MHz  #实测  2026-09-17
stm32_usart1clk = 64 MHz  @HSI  #推导  2026-08-24
stm32_fdcanclk = 8 MHz  @HSE  #推导  2026-08-24

## 调试通道
dbg_channel = RTT  @cl_config.h RTT_DBG=1/UART_DBG=0  #用户  2026-09-18
rtt_buffer_up = 1024 B  @SEGGER_RTT_Conf.h BUFFER_SIZE_UP  #推导  2026-09-18

## 主循环时序
main_loop_typ_us = 1  @main while(1) tag2抽稀500:1  #实测  2026-09-18
main_loop_worst_us = 625  @1Hz心跳圈tag5(含12×SPI读)  #实测  2026-09-18

## 高速边界 (24V+传送带)
vmax_stall_U2_rpm = (1462,1481]  @vel二分+RTT enc冻结判  #实测  2026-09-18
vmax_stall_U1_rpm = (1500,1572]  @U1@1481零滑动, 1572丢  #实测  2026-09-18
vel_cmd_unit = 寄存器原值  @SetVelocity直写VMAX, 物理=值/1.1178  #实测  2026-09-18
profile5_vmax = 572303  @10rps×51200×2^24/15e6, 600rpm生产档  #推导  2026-09-18
profile5_amax = 28000  @40000试探干净×0.7, 56rev/s²  #实测  2026-09-18
profile6_amax = 39200  @40000试探干净×0.98, 极限语义  #实测  2026-09-18
profile14_amax = 28000  @40000试探干净×0.7, G1~G4统一  #实测  2026-09-18
profile6_vmax = 1375452  @1442rpm=1471×0.98, 弱电机U2边界内  #推导  2026-09-18
profile6_scope = 极限运行专用  @生产禁用·值守·用后查失步  #你  2026-09-18

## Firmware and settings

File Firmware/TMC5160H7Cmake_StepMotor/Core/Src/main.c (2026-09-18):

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
/* Includes ------------------------------------------------------------------*/
#include "main.h"
#include "fdcan.h"
#include "spi.h"
#include "tim.h"
#include "usart.h"
#include "gpio.h"

/* USER CODE BEGIN Includes */
#include "algo/queue.h"
#include "drv/can.h"
#include "drv/uart_dbg.h"
#include "drv/rtt_dbg.h"
#include "drv/tmc5160.h"
#include "app/motor_ctrl.h"
#include "app/closed_loop.h"
#include "app/homing.h"
#include "comm_test.h"
#include "tim_test.h"
/* USER CODE END Includes */


/* USER CODE BEGIN PV */
/* 闭环节拍标志：预留（目标板无 TIM7，闭环 Tick 暂未启用，与源工程行为等价） */
volatile uint8_t g_cl_tick_flag = 0;
/* USER CODE END PV */

void SystemClock_Config(void);
void PeriphCommonClock_Config(void);
static void MPU_Config(void);
/**
  * @brief  The application entry point.
  * @retval int
  */
int main(void)
{

  /* MPU Configuration--------------------------------------------------------*/
  MPU_Config();

  /* MCU Configuration--------------------------------------------------------*/

  /* Reset of all peripherals, Initializes the Flash interface and the Systick. */
  HAL_Init();

  /* Configure the system clock */
  SystemClock_Config();

  /* Configure the peripherals common clocks */
  PeriphCommonClock_Config();

  /* Initialize all configured peripherals */
  MX_GPIO_Init();
  MX_FDCAN2_Init();
  MX_SPI3_Init();
  MX_TIM4_Init();
  MX_USART1_UART_Init();
  /* USER CODE BEGIN 2 */
  /* TMC5160 外部时钟: TIM4_CH3 PWM 输出 15MHz (TIM4CLK=240MHz/(PSC=0)/(ARR=15+1))
   * 必须在 TMC5160_Init 前启动，否则芯片无 fCLK 不工作 */
  HAL_TIM_PWM_Start(&htim4, TIM_CHANNEL_3);

  QUEUE_Init(&g_queue_st);
  CAN_Init();
  TMC5160_Init();
  MOTOR_Init();
  CLOSEDLOOP_Init();
  UART_DBG_Init();
  RTT_DBG_Init(); /* RTT 初始化（J-Link RTT Viewer 调试回传） */
  UART_DBG_Str("UART ready 115200\r\n");
  RTT_DBG_Str("RTT ready\r\n");
  UART_DBG_Str("[BOOT] TMC5160H7 StepMotor\r\n");
  RTT_DBG_Str("[BOOT] TMC5160H7 StepMotor\r\n");
#ifdef CL_TIMING_MEASURE
  TEST_TIM_Init();
  TEST_SPI_SaleaeTriggerInit();
  UART_DBG_Str("[SALEAE] 3-wire SCK PC10 MOSI PC12 MISO PC11 TRIG PA4\r\n");
#endif

  /* == 测试函数 == */
  /* 上电 SPI 自检：双芯 GSTAT/DRVSTATUS 回读，串口+RTT 双通道输出判据 */
  // COMM_Test_SPI();
#if SPI_SOAK
  /* SPI 位保真浸泡诊断（2026-09-10 电机排查轮，实现见 test/comm_test.c；
   * 含 U2 速度模式运转 10s，结束自动停并恢复 ENC_CONST；生产版置 0） */
  COMM_Test_SPI_Soak();
#endif
#if SPI_QUIET
  /* 静音模式(StealthChop)电机运行测试（2026-09-10 用户定案，实现见
   * test/comm_test.c；判据=转+无故障，S2 保持开启；结束恢复 GCONF=0x00） */
  COMM_Test_SPI_Quiet();
#endif
#if SPI_MANUAL
  /* 手册(ch22/ch23)基线配置+一整圈定位运转（2026-09-10 用户定案，实现见
   * test/comm_test.c；判据=|enc|≥25600 且 S2/drv_err 全 0；VS=24V+VSA=12V 实况） */
  COMM_Test_ManualRun();
#endif
#if SPI_PRODRUN
  /* 生产配置 SpreadCycle 整圈运行验证（2026-09-12 用户定案，实现见
   * test/comm_test.c；判据=到位且全程无错误标志+enc跟随；生产版置 0） */
  COMM_Test_ProdRun();
#endif
#if SPI_PRODRUN_U1
  /* U1 生产配置 SpreadCycle 整圈运行验证（2026-09-14 新增，
   * 实现见 test/comm_test.c COMM_Test_ProdRun_U1()；
   * 判据对标 PRODRUN；生产版置 0） */
  COMM_Test_ProdRun_U1();
#endif

  /* USER CODE END 2 */

  /* Infinite loop */
  /* USER CODE BEGIN WHILE */
  while (1)
  {
    /* [TM] tag2=主循环单圈(抽稀500:1,避RTT回传反压) / tag5=1Hz心跳SPI诊断块
     * 依据 probe.md DWT序列 + memory stm32_dwt_cyccnt_clk=480MHz(CPU=SYSCLK,实测481MHz 2026-09-17)
     * 回传经 printf->_write->RTT Ch0(09-18切RTT,串口不可用),生产版空宏零开销 */
#ifdef CL_TIMING_MEASURE
    static uint32_t s_tm2_cnt = 0;
    ++s_tm2_cnt;
    if ((s_tm2_cnt % 500U) == 0U)
    {
        TEST_TIM_Start(2); /* 抽稀: 每500圈测一圈, Start/Stop配对 */
    }
#else
    TEST_TIM_Start(2); /* 生产版空宏 */
#endif
#ifdef CL_TIMING_MEASURE
    /* 3-wire Saleae 连续触发: 每 10ms 一次 U2 GSTAT 读, PA4 窄脉冲作同步 */
    {
        static uint32_t s_saleae_last = 0;
        if ((HAL_GetTick() - s_saleae_last) >= 10)
        {
            s_saleae_last = HAL_GetTick();
            TEST_SPI_SaleaePulse();
            (void)TMC5160_SpiRead(TMC5160_CHIP_2, 0x01); /* GSTAT */
        }
    }
#endif
    CAN_Process();
    HOME_Tick();
    COMM_Test_CAN_Heartbeat();
    /* 双通道心跳遥测：1Hz 打印双电机实际/编码器位置 (USART1 115200 + RTT) */
    {
      static uint32_t s_rtt_last_tick = 0;
      uint32_t now = HAL_GetTick();
      if ((now - s_rtt_last_tick) >= 1000)
      {
        s_rtt_last_tick = now;
        TEST_TIM_Start(5); /* tag5=1Hz心跳SPI诊断块(含4次读事务) */
        /* U2 追加运动诊断量: v=VACTUAL(0x22) rs=RAMP_STAT cs=CS_ACTUAL[9:0]
         * ds=DRVSTATUS(OL/OT/S2 位) gs=GSTAT —— 遥测先行定位抖动 (retrieval.md) */
        {
          TMC5160_CHIP_T *u2 = MOTOR_GetChip(MOTOR_CTRL_U2);
          uint32_t ds = TMC5160_GetDrvStatus(u2);
          UART_DBG_Printf("[t=%u] U1 act=%d enc=%d | U2 act=%d enc=%d "
                          "v=%d rs=%lX cs=%lu ds=%08lX gs=%02X\r\n",
                          (unsigned)now,
                          (int)MOTOR_GetPosition(MOTOR_CTRL_U1),
                          (int)MOTOR_GetEncoderPosition(MOTOR_CTRL_U1),
                          (int)MOTOR_GetPosition(MOTOR_CTRL_U2),
                          (int)MOTOR_GetEncoderPosition(MOTOR_CTRL_U2),
                          (int)TMC5160_GetVelocity(u2),
                          (unsigned long)TMC5160_GetRampStat(u2),
                          (unsigned long)(ds & 0x3FFUL),
                          (unsigned long)ds,
                          (unsigned int)TMC5160_GetGStat(u2));
        }
        RTT_DBG_Printf("[t=%u] U1 act=%d enc=%d | U2 act=%d enc=%d\r\n",
                       (unsigned)now,
                       (int)MOTOR_GetPosition(MOTOR_CTRL_U1),
                       (int)MOTOR_GetEncoderPosition(MOTOR_CTRL_U1),
                       (int)MOTOR_GetPosition(MOTOR_CTRL_U2),
                       (int)MOTOR_GetEncoderPosition(MOTOR_CTRL_U2));
        TEST_TIM_Stop(5);
      }
    }

    /* 闭环控制：目标板无 TIM7 节拍定时器，保持注释态（与源工程行为等价） */
    // if (g_cl_tick_flag)
    // {
    //   g_cl_tick_flag = 0;
    //   CLOSEDLOOP_Tick(MOTOR_CTRL_U1);
    //   CLOSEDLOOP_Tick(MOTOR_CTRL_U2);
    // }

#ifdef CL_TIMING_MEASURE
    if ((s_tm2_cnt % 500U) == 0U)
    {
        TEST_TIM_Stop(2); /* 与顶部Start配对, 1次/500圈 */
    }
#else
    TEST_TIM_Stop(2); /* 生产版空宏 */
#endif
    /* USER CODE END WHILE */

    /* USER CODE BEGIN 3 */
  }
  /* USER CODE END 3 */
}

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
 /* MPU Configuration */

void MPU_Config(void)
{
  MPU_Region_InitTypeDef MPU_InitStruct = {0};

  /* Disables the MPU */
  HAL_MPU_Disable();

  /** Initializes and configures the Region and the memory to be protected
  */
  MPU_InitStruct.Enable = MPU_REGION_ENABLE;
  MPU_InitStruct.Number = MPU_REGION_NUMBER0;
  MPU_InitStruct.BaseAddress = 0x0;
  MPU_InitStruct.Size = MPU_REGION_SIZE_4GB;
  MPU_InitStruct.SubRegionDisable = 0x87;
  MPU_InitStruct.TypeExtField = MPU_TEX_LEVEL0;
  MPU_InitStruct.AccessPermission = MPU_REGION_NO_ACCESS;
  MPU_InitStruct.DisableExec = MPU_INSTRUCTION_ACCESS_DISABLE;
  MPU_InitStruct.IsShareable = MPU_ACCESS_SHAREABLE;
  MPU_InitStruct.IsCacheable = MPU_ACCESS_NOT_CACHEABLE;
  MPU_InitStruct.IsBufferable = MPU_ACCESS_NOT_BUFFERABLE;

  HAL_MPU_ConfigRegion(&MPU_InitStruct);
  /* Enables the MPU */
  HAL_MPU_Enable(MPU_PRIVILEGED_DEFAULT);

}

/**
  * @brief  This function is executed in case of error occurrence.
  * @retval None
  */
void Error_Handler(void)
{
  /* USER CODE BEGIN Error_Handler_Debug */
  /* User can add his own implementation to report the HAL error return state */
  __disable_irq();
  while (1)
  {
  }
  /* USER CODE END Error_Handler_Debug */
}
#ifdef USE_FULL_ASSERT
/**
  * @brief  Reports the name of the source file and the source line number
  *         where the assert_param error has occurred.
  * @param  file: pointer to the source file name
  * @param  line: assert_param error line source number
  * @retval None
  */
void assert_failed(uint8_t *file, uint32_t line)
{
  /* USER CODE BEGIN 6 */
  /* User can add his own implementation to report the file name and line number,
     ex: printf("Wrong parameters value: file %s on line %d\r\n", file, line) */
  /* USER CODE END 6 */
}
#endif /* USE_FULL_ASSERT */

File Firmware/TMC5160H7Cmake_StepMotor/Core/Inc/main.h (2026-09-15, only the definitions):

#define LED_MCU_Pin GPIO_PIN_4
#define LED_MCU_GPIO_Port GPIOA
#define TMC_CLK_Pin GPIO_PIN_14
#define TMC_CLK_GPIO_Port GPIOD
#define U1_DRV_ENN_Pin GPIO_PIN_10
#define U1_DRV_ENN_GPIO_Port GPIOA
#define U1_SPI_SCN_Pin GPIO_PIN_11
#define U1_SPI_SCN_GPIO_Port GPIOA
#define U2_DRV_ENN_Pin GPIO_PIN_15
#define U2_DRV_ENN_GPIO_Port GPIOA
#define U2_SPI_SCN_Pin GPIO_PIN_3
#define U2_SPI_SCN_GPIO_Port GPIOD

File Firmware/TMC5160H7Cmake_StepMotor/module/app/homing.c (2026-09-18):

/*****************************************************************************
 * @文件: homing.c
 * @作者: cl
 * @日期: 2026-09-12
 * @版本: v1.0
 * @说明: 无编码器回零编排层（StallGuard2 堵转检测碰硬限位，不用编码器）
 *        标准流程依据 ch13 §13.4：硬限位方向速度运动 → 堵转 →
 *        反向回退防卡死 → XACTUAL 写 0 标定零点
 *        芯片级 SG 原语在 drv/tmc5160（TMC5160_Home*）；本层负责状态机/时序，
 *        运动经 app/motor_ctrl（保持闭环命令目标 s_cmd_target 同步）
 * @依赖: drv/tmc5160(SG 原语/位置), drv/can(完成反馈), app/motor_ctrl(运动), drv/uart_dbg
 ****************************************************************************/
#include "app/homing.h"
#include "app/motor_ctrl.h"
#include "drv/tmc5160.h"
#include "drv/can.h"
#include "drv/uart_dbg.h"
#include "main.h"

/* ==== 确认与超时 ==== */
/* SG 轮询周期: fullstep 周期@2RPS=1/(2×200)=2.5ms, 取 2ms 覆盖每 fullstep
 * 依据 .cl/memory/config.md home_sg_poll_ms=2
 * （SG_RESULT 随 fullstep 更新, ch13 §13.1） */
#define HOME_SG_POLL_MS    2U
/* 连续零确认次数（用户 2026-09-12 定） */
#define HOME_SG_CONFIRM    8U
/* 反向回退步数（用户 2026-09-12 定） */
#define HOME_BO_STEPS      2048L
/* 寻零超时：机械行程未知，2RPS 下 30s=60 转上限兜底（待实测确认）
 * 依据 .cl/memory/config.md home_run_timeout_ms=30000 */
#define HOME_RUN_TIMEOUT   30000U
/* 回退到位超时：2048µsteps 三角斜坡约 60ms(AMAX≈2.05M µsteps/s²)，取 10s 兜底堵死
 * （待实测确认）依据 .cl/memory/config.md home_bo_timeout_ms=10000 */
#define HOME_BO_TIMEOUT    10000U

/* ==== 内部状态 ==== */
static HOME_STATE_T s_state = HOME_IDLE;
static uint8_t s_motor = 0;
static int8_t s_seek_sign = 0;   /* +1 正向寻零 / -1 负向寻零 */
static uint8_t s_confirm = 0;
static uint8_t s_stable = 0;
static uint32_t s_last_poll = 0;
static uint32_t s_t_mark = 0;
static int32_t s_bo_target = 0;
static uint8_t s_result = 1;      /* 0=成功，1=失败/未完成 */
static uint32_t s_last_trace = 0; /* SG 跟踪打印节流（SGT 调定后删除） */

/* ==== 内部工具 ==== */

/**
 * @输入 ok: 1=成功(DONE)，0=失败/超时(FAIL)
 * @输出 无
 * @说明 进入终态：停车(经 MOTOR_Stop 同步闭环目标)→恢复现场→发 CAN 反馈
 * @注意 改全局状态机并发反馈帧；MOTOR_Stop 保持闭环命令目标一致
 */
static void S_Finish(uint8_t ok)
{
    TMC5160_CHIP_T *chip = MOTOR_GetChip(s_motor);

    if ((void *)0 != chip)
    {
        MOTOR_Stop(s_motor);
        TMC5160_HomeRestore(chip);
    }
    if (0U != ok)
    {
        s_state = HOME_DONE;
        s_result = 0;
        CAN_SendMotionFeedback(s_motor, 0, STATUS_DONE, 0);
    }
    else
    {
        s_state = HOME_FAIL;
        s_result = 1;
        CAN_SendMotionFeedback(s_motor, 0, STATUS_STALL, 0);
    }
}

/**
 * @输入 无
 * @输出 无
 * @说明 堵转确认后转入回退段：停车→反向回退 HOME_BO_STEPS→登记回退目标
 *        回退方向与寻零方向相反（防卡死在限位）；运动经 MOTOR_MoveBy(同步闭环目标)
 */
static void S_EnterBackoff(void)
{
    TMC5160_CHIP_T *chip = MOTOR_GetChip(s_motor);
    int32_t backoff;

    MOTOR_Stop(s_motor);
    backoff = (0 < s_seek_sign) ? -HOME_BO_STEPS : HOME_BO_STEPS;
    MOTOR_MoveBy(s_motor, backoff);
    if ((void *)0 != chip)
    {
        s_bo_target = TMC5160_GetPosition(chip) + backoff;
    }
    s_stable = 0;
    s_t_mark = HAL_GetTick();
    s_state = HOME_BACKOFF;
}

/* ==== 接口实现 ==== */

/**
 * @输入 motor: 电机编号(U1/U2)；dir: 方向(TMC5160_HOME_DIR_*)
 * @输出 0=已启动，1=忙（上次未取走结果），2=参数非法
 * @说明 配置 SG 检测并以速度模式撞向硬限位；非阻塞
 * @注意 仅单电机（无 ALL）；终态(DONE/FAIL)允许直接重启动
 */
uint8_t HOME_Start(uint8_t motor, uint8_t dir)
{
    TMC5160_CHIP_T *chip;

    /* 仅 RUN/BACKOFF 算忙（终态反馈已发出，HOME_TakeResult 仅供查询） */
    if (HOME_RUN == s_state || HOME_BACKOFF == s_state)
    {
        return 1;   /* 忙：上一次回零仍在进行（RUN/BACKOFF） */
    }
    chip = MOTOR_GetChip(motor);
    if (((void *)0 == chip) ||
        (TMC5160_HOME_DIR_POSITIVE != dir && TMC5160_HOME_DIR_NEGATIVE != dir))
    {
        return 2;   /* 参数非法：电机编号无效(非 U1/U2) 或方向非法 */
    }

    s_motor = motor;
    s_seek_sign = (TMC5160_HOME_DIR_POSITIVE == dir) ? 1 : -1;
    s_confirm = 0;

    /* 配置 SG 检测（芯片级原语在 drv/tmc5160） */
    TMC5160_HomeConfig(chip);

    /* 速度模式撞向限位（sg_stop 硬件兜底，软件 N 确认主判） */
    if (0 < s_seek_sign)
    {
        MOTOR_SetVelocity(motor, (int32_t)TMC5160_HOME_VMAX);
    }
    else
    {
        MOTOR_SetVelocity(motor, -(int32_t)TMC5160_HOME_VMAX);
    }
    s_last_poll = HAL_GetTick();
    s_t_mark = s_last_poll;
    s_state = HOME_RUN;
    return 0;
}

/**
 * @输入 无
 * @输出 无
 * @说明 主循环每圈调用，推进寻零/回退状态机；终态发 CAN 反馈
 */
void HOME_Tick(void)
{
    TMC5160_CHIP_T *chip;
    uint32_t now;
    uint16_t sg;

    if (HOME_RUN != s_state && HOME_BACKOFF != s_state)
    {
        return;
    }
    chip = MOTOR_GetChip(s_motor);
    if ((void *)0 == chip)
    {
        S_Finish(0);
        return;
    }
    now = HAL_GetTick();

    if (HOME_RUN == s_state)
    {
        /* 超时：未碰到限位（电机脱开/行程超限） */
        if ((now - s_t_mark) >= HOME_RUN_TIMEOUT)
        {
            S_Finish(0);
            return;
        }
        if ((now - s_last_poll) < HOME_SG_POLL_MS)
        {
            return;
        }
        s_last_poll = now;

        /* 硬件备份：sg_stop 已触发 event_stop_sg（读+清，drv 原语） */
        if (0U != TMC5160_HomeCheckStall(chip))
        {
            S_EnterBackoff();
            return;
        }

        /* 主判据：SG_RESULT 连续零确认（用户 2026-09-12 定） */
        sg = TMC5160_HomeGetSg(chip);
        /* SGT 调定诊断：寻零期间每 500ms 打印 SG（调定后删除） */
        if ((now - s_last_trace) >= 500U)
        {
            s_last_trace = now;
            UART_DBG_Printf("[HOME sg] sg=%u v=%ld n=%u\r\n",
                            (unsigned)sg,
                            (long)TMC5160_GetVelocity(chip),
                            (unsigned)s_confirm);
        }
        if (0U == sg)
        {
            s_confirm++;
            if (s_confirm >= HOME_SG_CONFIRM)
            {
                S_EnterBackoff();
                return;
            }
        }
        else
        {
            s_confirm = 0;
        }
    }
    else /* HOME_BACKOFF */
    {
        /* 超时：回退未到位 */
        if ((now - s_t_mark) >= HOME_BO_TIMEOUT)
        {
            S_Finish(0);
            return;
        }
        if ((now - s_last_poll) < 10U)
        {
            return;
        }
        s_last_poll = now;

        /* 到位轮询：XACTUAL 连续 2 次 == 目标 */
        if (s_bo_target == TMC5160_GetPosition(chip))
        {
            s_stable++;
            if (s_stable >= 2U)
            {
                /* 标定零点（ch06.p040：homing 时允许改 XACTUAL） */
                TMC5160_HomeZero(chip);
                MOTOR_Stop(s_motor);
                TMC5160_HomeRestore(chip);
                s_state = HOME_DONE;
                s_result = 0;
                CAN_SendMotionFeedback(s_motor, 0, STATUS_DONE, 0);
            }
        }
        else
        {
            s_stable = 0;
        }
    }
}

/* 查询当前状态 */
HOME_STATE_T HOME_GetState(void)
{
    return s_state;
}

/**
 * @输出 0=成功，1=失败/未完成
 * @说明 取走终态结果并回 IDLE（仅终态有效）
 */
uint8_t HOME_TakeResult(void)
{
    uint8_t r = s_result;

    if (HOME_DONE == s_state || HOME_FAIL == s_state)
    {
        s_state = HOME_IDLE;
        s_result = 1;
    }
    return r;
}

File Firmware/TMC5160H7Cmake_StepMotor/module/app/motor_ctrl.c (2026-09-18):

/*****************************************************************************
 * @文件: motor_ctrl.c
 * @作者: cl
 * @日期: 2026-08-25
 * @版本: v1.0
 * @说明: 电机控制中间层（封装电机选择 + 运动执行）
 * @来源: 自 TMC5160_StepMotor(F407) 移植归一，行为等价（纯逻辑零适配）
 * @依赖: drv/tmc5160, app/closed_loop
 ****************************************************************************/
#include "app/motor_ctrl.h"
#include "drv/tmc5160.h"
#include "app/closed_loop.h"

/* ==== 内部工具 ==== */

/**
 * @输入 motor: 电机编号
 * @输出 TMC5160_CHIP_T*: 芯片指针，无效编号返回 NULL
 * @说明 根据电机编号获取 TMC5160 芯片指针
 */
TMC5160_CHIP_T *MOTOR_GetChip(uint8_t motor)
{
    if (MOTOR_CTRL_U1 == motor)
    {
        return &g_tmc5160_chip1_st;
    }
    else if (MOTOR_CTRL_U2 == motor)
    {
        return &g_tmc5160_chip2_st;
    }
    return (void *)0;
}

/* ==== 接口实现 ==== */

/**
 * @输入 无
 * @输出 无
 * @说明 电机控制模块初始化（实际由 TMC5160_Init 完成）
 */
void MOTOR_Init(void)
{
    /* 初始化由 TMC5160_Init() 完成，此处无需额外操作 */
}

/**
 * @输入 motor: 电机编号; target: 目标绝对位置
 * @输出 无
 * @说明 运动到目标位置，支持单电机或全部电机
 */
void MOTOR_MoveTo(uint8_t motor, int32_t target)
{
    if (MOTOR_CTRL_ALL == motor)
    {
        TMC5160_MoveTo(&g_tmc5160_chip1_st, target);
        CLOSEDLOOP_SetTarget(MOTOR_CTRL_U1, target);
        TMC5160_MoveTo(&g_tmc5160_chip2_st, target);
        CLOSEDLOOP_SetTarget(MOTOR_CTRL_U2, target);
    }
    else
    {
        TMC5160_CHIP_T *chip = MOTOR_GetChip(motor);
        if ((void *)0 != chip)
        {
            TMC5160_MoveTo(chip, target);
            CLOSEDLOOP_SetTarget(motor, target);
        }
    }
}

/**
 * @输入 motor: 电机编号; offset: 相对偏移量(+正转, -反转)
 * @输出 无
 * @说明 运动指定偏移量
 */
void MOTOR_MoveBy(uint8_t motor, int32_t offset)
{
    if (MOTOR_CTRL_ALL == motor)
    {
        int32_t t1 = TMC5160_GetPosition(&g_tmc5160_chip1_st) + offset;
        int32_t t2 = TMC5160_GetPosition(&g_tmc5160_chip2_st) + offset;
        TMC5160_MoveBy(&g_tmc5160_chip1_st, offset);
        CLOSEDLOOP_SetTarget(MOTOR_CTRL_U1, t1);
        TMC5160_MoveBy(&g_tmc5160_chip2_st, offset);
        CLOSEDLOOP_SetTarget(MOTOR_CTRL_U2, t2);
    }
    else
    {
        TMC5160_CHIP_T *chip = MOTOR_GetChip(motor);
        if ((void *)0 != chip)
        {
            int32_t final = TMC5160_GetPosition(chip) + offset;
            TMC5160_MoveBy(chip, offset);
            CLOSEDLOOP_SetTarget(motor, final);
        }
    }
}

/**
 * @输入 motor: 电机编号; velocity: 目标速度(+正转, -反转)
 * @输出 无
 * @说明 切换速度模式持续旋转
 */
void MOTOR_SetVelocity(uint8_t motor, int32_t velocity)
{
    if (MOTOR_CTRL_ALL == motor)
    {
        TMC5160_SetVelocity(&g_tmc5160_chip1_st, velocity);
        TMC5160_SetVelocity(&g_tmc5160_chip2_st, velocity);
    }
    else
    {
        TMC5160_CHIP_T *chip = MOTOR_GetChip(motor);
        if ((void *)0 != chip)
        {
            TMC5160_SetVelocity(chip, velocity);
        }
    }
}

/**
 * @输入 motor: 电机编号
 * @输出 无
 * @说明 停止电机，切回定位模式保持锁轴
 */
void MOTOR_Stop(uint8_t motor)
{
    if (MOTOR_CTRL_ALL == motor)
    {
        int32_t p1 = TMC5160_GetPosition(&g_tmc5160_chip1_st);
        int32_t p2 = TMC5160_GetPosition(&g_tmc5160_chip2_st);
        TMC5160_Stop(&g_tmc5160_chip1_st);
        CLOSEDLOOP_SetTarget(MOTOR_CTRL_U1, p1);
        TMC5160_Stop(&g_tmc5160_chip2_st);
        CLOSEDLOOP_SetTarget(MOTOR_CTRL_U2, p2);
    }
    else
    {
        TMC5160_CHIP_T *chip = MOTOR_GetChip(motor);
        if ((void *)0 != chip)
        {
            int32_t pos = TMC5160_GetPosition(chip);
            TMC5160_Stop(chip);
            CLOSEDLOOP_SetTarget(motor, pos);
        }
    }
}

/**
 * @输入 motor: 电机编号; group: 运动参数组 ID(1~5)
 * @输出 无
 * @说明 应用预定义运动参数组
 */
void MOTOR_ApplyProfile(uint8_t motor, uint8_t group)
{
    if (MOTOR_CTRL_ALL == motor)
    {
        TMC5160_ApplyProfile(&g_tmc5160_chip1_st, group);
        TMC5160_ApplyProfile(&g_tmc5160_chip2_st, group);
    }
    else
    {
        TMC5160_CHIP_T *chip = MOTOR_GetChip(motor);
        if ((void *)0 != chip)
        {
            TMC5160_ApplyProfile(chip, group);
        }
    }
}

/**
 * @输入 motor: 电机编号
 * @输出 int32_t: 当前位置，无效电机返回 0
 */
int32_t MOTOR_GetPosition(uint8_t motor)
{
    TMC5160_CHIP_T *chip = MOTOR_GetChip(motor);

    if ((void *)0 != chip)
    {
        return TMC5160_GetPosition(chip);
    }
    return 0;
}

/**
 * @输入 motor: 电机编号
 * @输出 int32_t: 编码器当前位姿(X_ENC 归零后)
 */
int32_t MOTOR_GetEncoderPosition(uint8_t motor)
{
    TMC5160_CHIP_T *chip = MOTOR_GetChip(motor);

    if ((void *)0 != chip)
    {
        return TMC5160_GetEncoderPosition(chip);
    }
    return 0;
}

/**
 * @输入 motor: 电机编号
 * @输出 int32_t: X_ENC - XACTUAL 偏差（绝对值）
 */
int32_t MOTOR_GetEncoderDeviation(uint8_t motor)
{
    TMC5160_CHIP_T *chip = MOTOR_GetChip(motor);

    if ((void *)0 != chip)
    {
        int32_t x_act = TMC5160_GetPosition(chip);
        int32_t x_enc = TMC5160_GetEncoderPosition(chip);
        return x_enc - x_act;
    }
    return 0;
}

/**
 * @输入 motor: 电机编号
 * @输出 uint8_t: 状态标志位
 */
uint8_t MOTOR_GetStatus(uint8_t motor)
{
    TMC5160_CHIP_T *chip = MOTOR_GetChip(motor);

    if ((void *)0 != chip)
    {
        return TMC5160_GetStatusFlags(chip);
    }
    return 0;
}

/**
 * @输入 motor: 电机编号
 * @输出 uint8_t: 运动阶段标志
 */
uint8_t MOTOR_GetStage(uint8_t motor)
{
    TMC5160_CHIP_T *chip = MOTOR_GetChip(motor);

    if ((void *)0 != chip)
    {
        return TMC5160_GetMotionPhase(chip);
    }
    return 0;
}

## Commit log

2026-09-15 完成软硬件测试
    [NBNZY_AD_LIB.PcbLib, NBNZY_AD_LIB.SchLib, StepMotor_TMC5160.PrjPcb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]
2026-09-17 cl: .cl 权威内容纳入版本控制（清理前快照）
2026-09-17 cl: SPI 寄存器级收发+片选改造 + DWT 基准修正 完成(验收通过); 含 drv/app/algo 重构 + .cl 按 v4.6.0 规范重整(精简 memory/修矛盾/清 init 产物与 capture 日志)
    [can.c, cl_config.h, closed_loop.c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]
2026-09-17 cl: require.md 按模板重构 + 附录段 (CAN协议/工作流程移至附录, gon 跳过) + memory 补 FDCAN2
2026-09-17 cl: 任务队列人工验收完成（除失步标志[!]外全部[✓]）
2026-09-17 cl: memory 加『定论(已否决/已解决·勿重开)』段并收敛 u2_kelvin/SPE 重复项
2026-09-17 cl: require 任务队列滚动精简(保留未完成[!]+最近5条已完成, 197->168 行)
2026-09-17 cl: memory 重排 terse (key=value @依据 #来源 日期; 10.7KB->7.5KB)
2026-09-17 cl: tmc5160.c 注释精简(依据集中函数头/删历史/去路径前缀) + index CN 归档
2026-09-17 cl: 注释依据去路径前缀(.cl/datasheet/pages/ 省略) 机械化统一
2026-09-17 cl: tmc5160.c 依据行恢复手册寄存器名 DRV_CONF(gate 已修注释误报)
2026-09-17 cl: tmc5160.c 体内依据上移函数头/删历史(TMC5160_Init 续)
2026-09-18 cl: 双TMC5160速度极限/边界/加速度优化完成 (验收通过)
    - 速度二分: U2∈(1462,1481]rpm, U1∈(1500,1572]rpm, 600rpm裕量2.4×
    - 加速度优化: G1~G5=28000(×0.7), G6=39200(×0.98), DMAX=AMAX对称
    - Group6=1442rpm极限运行档(生产禁用,值守,用后查失步位)
    - ENC_TOLERANCE 256→512µsteps(覆盖G6巡航滞后263µsteps)
    - RTT调试通道切换(UART→RTT Channel 0)
    - SPI寄存器级收发+片选(DWT 480MHz基准修正)
    - 代码风格重构(DRV_/USR_→S_+表意裸名)
    - .cl/权威内容纳入版本控制(供log/memory精简git兜底)
    - tools/构建/烧录/调试工具链完整收录
    - 验收: format_gate 0FAIL, build 0E/0W, FLASH 44636B
    [_watcher.py, can.c, can_monitor.py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]

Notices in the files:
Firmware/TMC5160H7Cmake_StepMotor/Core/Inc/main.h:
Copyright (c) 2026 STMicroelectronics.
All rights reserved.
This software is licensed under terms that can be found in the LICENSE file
